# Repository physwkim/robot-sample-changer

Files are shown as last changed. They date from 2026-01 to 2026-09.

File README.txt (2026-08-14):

================================================================================
                    UR3e + Robotiq HandE 로봇 시스템
                       순수 Rust 스택 (ROS 없음)
================================================================================

1. 개요
--------------------------------------------------------------------------------
이 시스템은 UR3e 로봇 암과 Robotiq HandE 그리퍼로 자동화된 샘플 홀더 교환
시퀀스를 수행합니다. 제어는 단일 Rust 데몬(robot-sequencer)이 담당합니다:

    - 로봇 구동: ur-driver (RTDE, 로봇에 직접 접속 — ROS 드라이버 대체)
    - 모션 플래닝/IK: cspace (Rust MoveIt 포트 — MoveIt 대체)
    - 그리퍼: robotiq-hande (TCP 54321 직접 Modbus RTU)
    - 외부 연동: EPICS CA (epics-ca-rs — robot_ioc의 PV 읽기/쓰기)

ROS2/MoveIt/colcon은 더 이상 필요 없습니다.

2. 시스템 요구사항
--------------------------------------------------------------------------------
- Ubuntu 22.04
- Rust toolchain (cargo)
- sibling 체크아웃: ~/ur-driver, ~/cspace, ~/epics-rs (robot_sequencer 빌드용)
- UR 로봇 IP: 192.168.192.10
- 로봇은 Remote Control 모드 (펜던트 프로그램 실행 불필요 — 데몬이
  headless로 external control 프로그램을 전송)

3. 빌드 방법
--------------------------------------------------------------------------------
    export PATH="$HOME/.cargo/bin:$PATH"
    cd ~/ws/src/robot_sequencer
    cargo build --release

EPICS IOC(robot_ioc)와 모니터링 IOC는 별도 빌드:

    cd ~/ws/src/epics_rs_robot && cargo build --release -p robot_ioc
    cd ~/work/epics-rs-iocs && cargo build --release -p ur-robot-ioc

4. 실행 방법
--------------------------------------------------------------------------------
[1] EPICS IOC — 보통 systemd로 자동 실행됩니다 (procServ 콘솔 20001).
    수동 실행: ~/ws/src/epics_rs_robot/target/release/robot_ioc

[2] robot-sequencer 데몬 — 바탕화면 "1_Robot_Sequencer" 아이콘, 또는:

    ~/ws/src/robot_sequencer/target/release/robot-sequencer \
        ~/ws/config/sequencer.yaml

    시작하면 EPICS trigger 대기 상태가 됩니다. 로봇이 켜져 있고
    Remote Control 모드여야 합니다.

[3] Robot GUI (선택) — 바탕화면 "2_Robot_GUI" 아이콘 (conda env 자동).

[4] UR 모니터링 IOC (선택, 읽기 전용) — deploy/ur_monitor_ioc/ 참고.
    Robot:UR: prefix로 로봇 모드/조인트/TCP 상태를 CA로 노출.

URSim 리허설(하드웨어 없이 테스트): config/sequencer_ursim.yaml 사용.

5. 좌표계 설명
--------------------------------------------------------------------------------
이 시스템에서는 두 가지 좌표계를 사용합니다:

[Global Frame - 로봇 베이스 기준 좌표계]

    로봇을 정면에서 바라볼 때:

         Z (위)
         |
         |
         +------ Y (왼쪽)
        /
       /
      X (앞쪽, 로봇이 바라보는 방향)

    - X축: 로봇 전방 (Forward)
    - Y축: 로봇 왼쪽 (Left)
    - Z축: 위쪽 (Up, 중력 반대 방향)

[Local Frame - 엔드이펙터(TCP) 기준 좌표계]

    그리퍼 끝에서 바라볼 때:

         Y (아래)
         |
         |
         +------ X (오른쪽)
        /
       /
      Z (진행 방향, 그리퍼가 접근하는 방향)

    - X축: 오른쪽 (Right)
    - Y축: 아래쪽 (Down)
    - Z축: 진행 방향 (Forward/Approach)

* 주의: Local Frame은 엔드이펙터 기준이므로, 로봇 자세에 따라
  Global Frame과 방향이 다릅니다.

6. Waypoint 설정 방법
--------------------------------------------------------------------------------
웨이포인트 설정 파일 위치:
    ~/ws/config/taught_waypoints.yaml

[기본 웨이포인트 - 직접 티칭 필요]

4개의 기본 위치를 티칭해야 합니다:

    1. holder1_standby       - 홀더1 대기 위치
    2. holder1_on_position   - 홀더1 샘플 집는 위치
    3. sample_holder_standby - 샘플홀더 대기 위치
    4. sample_holder_on_position - 샘플홀더 놓는 위치

조인트 값 순서 (7개):
    [gripper, shoulder_pan, wrist_3, wrist_2, wrist_1, elbow, shoulder_lift]

[웨이포인트 티칭 방법]

1. 로봇을 원하는 위치로 수동 조작 (Freedrive 모드 사용)

2. 현재 조인트 값 확인 (택 1):
   - 티치펜던트의 Move 화면에서 조인트 값 읽기
   - 모니터링 IOC 실행 중이면:
       caget Robot:UR:Receive:ActualJointPositions
     (순서: shoulder_pan, shoulder_lift, elbow, wrist_1, wrist_2, wrist_3
      — 파일 순서와 다르므로 주의)

3. taught_waypoints.yaml 파일에서 해당 위치 값 수정

예시:
    holder1_on_position: [0.024, -1.327, 0.0001, -1.330, -3.301, -1.380, -1.600]

[오프셋 설정 - 미세 조정용]

티칭 후 미세 조정이 필요할 때 오프셋을 사용합니다 (단위: 미터):

    # Holder1 위치 오프셋 (Local Frame 기준)
    holder1_on_position_x_offset: 0.0015   # X축 오프셋 (+: 오른쪽)
    holder1_on_position_y_offset: 0.0      # Y축 오프셋 (+: 아래쪽)
    holder1_on_position_z_offset: -0.0005  # Z축 오프셋 (+: 진행방향)

    # Sample holder 위치 오프셋 (Local Frame 기준)
    sample_holder_on_position_x_offset: 0.0015
    sample_holder_on_position_y_offset: -0.0005
    sample_holder_on_position_z_offset: -0.0005

[자동 계산 웨이포인트]

다음 웨이포인트는 on_position에서 자동 계산됩니다:

    - above: on_position에서 Y 방향으로 5mm 위로 이동
    - retreat: above에서 Z 방향으로 50mm 후퇴

    above_y_offset: -0.005   # -5mm (Local Y, 위로)
    retreat_z_offset: -0.05  # -50mm (Local Z, 후퇴)

[멀티 홀더 오프셋]

홀더 2~10번에 대한 추가 오프셋 (홀더1 기준 상대값):

    # X축 추가 오프셋 (Index 0 = 홀더2, Index 8 = 홀더10)
    holder_multi_x_offsets: [0.000, 0.000, 0.000, 0.000, 0.0015, ...]

    # Z축 추가 오프셋
    holder_multi_z_offsets: [0.00025, 0.00020, 0.00020, ...]

[설정 변경 후]

트리거마다 파일을 다시 읽으므로 데몬 재시작이 필요 없습니다.
다음 Trigger=1 부터 새 값이 적용됩니다.

7. EPICS PV 제어 방법
--------------------------------------------------------------------------------
caput/caget으로 로봇을 제어할 수 있습니다:

시퀀스 시작:
    caput Robot:Trigger 1

시퀀스 일시정지 / 재개:
    caput Robot:Stop 1     # 현재 스텝 완료 후 일시정지
    caput Robot:Stop 0     # 재개

현재 스텝 확인:
    caget Robot:CurrentStep

홀더 번호 설정 (1-10):
    caput Robot:Holder 1

시작 스텝 설정:
    caput Robot:StartStep 0

지정 스텝에서 일시정지:
    caput Robot:PauseStep 15   # 스텝 15 완료 후 멈춤; 다른 값으로 바꾸면 재개

측정 대기 해제 (스텝 12 후):
    caput Robot:Wait 1     # 계속 (스텝 13-23 진행)
    caput Robot:Wait 2     # 나머지 스텝 skip

캘리브레이션 모드 설정:
    caput Robot:CalibMode 0    # 일반 모드 (전체 시퀀스)
    caput Robot:CalibMode 1    # Holder 캘리브레이션
    caput Robot:CalibMode 2    # Sample Holder 캘리브레이션

8. 캘리브레이션 모드 (위치 미세 조정)
--------------------------------------------------------------------------------
홀더 또는 샘플홀더 위치를 미세 조정할 때 사용합니다.
시료를 집어서 above 위치에서 멈추므로 중심 정렬을 확인할 수 있습니다.

[Holder 캘리브레이션 모드] (CalibMode = 1)

    목적: 홀더 위치 확인 및 조정
    동작: 스텝 0-5 수행 -> above에서 멈춤 -> 트리거 대기 -> 스텝 20-23 수행

    사용 방법:
    1. caput Robot:CalibMode 1
    2. caput Robot:Holder 5        # 확인할 홀더 번호
    3. caput Robot:Trigger 1       # 시작 -> 스텝 5에서 멈춤
    4. (시료를 잡은 상태에서 정렬 확인, 필요 시 TCP jog 사용)
    5. caput Robot:Trigger 1       # 시료 돌려놓기

[Sample Holder 캘리브레이션 모드] (CalibMode = 2)

    목적: 샘플홀더 위치 확인 및 조정
    동작: 스텝 0-8 수행 -> sample holder above에서 멈춤 -> 트리거 대기
          -> 스텝 16-23 수행

    사용 방법:
    1. caput Robot:CalibMode 2
    2. caput Robot:Holder 1        # 시료를 가져올 홀더 번호
    3. caput Robot:Trigger 1       # 시작 -> 스텝 8에서 멈춤
    4. (시료를 잡은 상태에서 샘플홀더 정렬 확인, 필요 시 TCP jog 사용)
    5. caput Robot:Trigger 1       # 시료 돌려놓기

[TCP Jog - hold 중 미세 이동]

캘리브레이션 hold 중에만 동작합니다. 방향은 TCP(Local Frame) 기준:

    caput Robot:JogStep 1.0    # 스텝 크기 (mm)
    caput Robot:JogX 1         # +X 방향으로 1스텝 (값: -1/0/+1)
    caput Robot:JogY -1
    caput Robot:JogZ 1

Jog PV는 실행 후 자동으로 0으로 리셋됩니다.

캘리브레이션 완료 후:
    caput Robot:CalibMode 0        # 일반 모드로 복귀

9. Vision 미세 보정 (기본 off)
--------------------------------------------------------------------------------
손목 카메라 노드가 Robot:Vision:* PV로 답하면 픽/플레이스 하강 직전
위치를 자동 보정합니다. config의 vision.enabled: true 로 켭니다
(기본 false — 꺼져 있으면 기존 동작과 완전히 동일).

동작 (Normal 모드 전용, 캘리브레이션 모드에는 적용되지 않음):
  - 스텝 1/12 (standby 도착 후): 픽 정렬 측정 → 스텝 2/3, 13/14 에 반영
  - 스텝 7/18 (standby 도착 후): 플레이스 정렬 측정 → 스텝 8/9, 19/20 에 반영
  - 스텝 5/16 상승 후: 그립 오프셋 측정 (다음 플레이스 보정에 합산)
  - 스텝 12/23 (standby 복귀 후): 안착(seating) 확인

측정은 above가 아니라 standby에서 합니다. above에서는 파지점이 480행짜리
화면보다 55행 아래로 투영되고 화면 중앙에는 한 칸 위 홀더가 잡힙니다
(doc/vision_correction_plan.md §12.4). standby에서는 같은 점이 (306, 330),
샘플홀더 시트가 (313, 277)로 중앙 부근입니다.

보정 게이트 (3축 합성 크기 기준):
  - min_correction (기본 0.05mm) 미만: 노이즈로 보고 무시
  - max_correction (기본 3.0mm) 이하: 적용
  - 초과: 에러 정지 — 자동 적용하지 않음. CurrentStep이 보존되므로
    원인 확인 후 아래 10. 재개 절차대로 StartStep으로 재개

vision.observe_only: true 면 측정하고 로그만 남기며 절대 이동/정지하지
않습니다 (카메라 검증 단계용).

카메라 없이 리허설: vision_sim이 고정 답으로 핸드셰이크에 응답합니다.
    ./target/release/vision_sim --dx 0.8 --dy -0.5

10. 충돌/중단 후 재개 (resume)
--------------------------------------------------------------------------------
상태는 EPICS PV에 보존됩니다 (autosave 포함 — 전원 재시작에도 유지).
CurrentStep > 0 이면 중단된 시퀀스입니다.

    1. caget Robot:CurrentStep         # 중단 지점 확인
    2. caput Robot:StartStep <스텝>    # 재개할 스텝 설정
    3. 프리드라이브로 로봇을 안전한 위치로 이동
    4. 티치펜던트에서 보호정지(protective stop) 해제
    5. caput Robot:Trigger 1           # 재개 (StartStep 미만 스텝 자동 skip)

11. 종료 방법
--------------------------------------------------------------------------------
robot-sequencer: 터미널 실행 시 Ctrl+C, 런처 실행 시 프로세스 종료.
robot_ioc(systemd): sudo systemctl stop robot-ioc

12. 문제 해결
--------------------------------------------------------------------------------
문제: 데몬이 "RTDE init: Input variable ... controlled by another RTDE client"
      오류로 종료됨
해결: 이전 robot-sequencer 프로세스가 남아 있는지 확인 후 종료
      (pgrep -a robot-sequencer). 모니터링 IOC는 receive 전용이라 무관.

문제: 로봇이 움직이지 않음
해결:
  1. 로봇이 Remote Control 모드인지 확인
  2. 보호정지/비상정지 상태 확인 (데몬이 시작 시 보호정지는 자동 해제 시도)
  3. 데몬 로그에서 bring-up 오류 확인

문제: 그리퍼가 동작하지 않음
해결:
  1. 펜던트에서 툴 통신 설정(RS485, 115200) 확인
  2. 로봇 IP로 TCP 54321 접속 가능한지 확인
  3. 다른 프로세스(이전 데몬)가 54321을 점유 중인지 확인

문제: PV가 보이지 않음 (caget 실패)
해결:
  1. robot_ioc 실행 확인 (telnet localhost 20001)
  2. 이 호스트에는 5064를 공유하는 CA 서버가 여럿 있습니다(d435i-ioc 등).
     ss -ulnp | grep 5064 로 확인. 로컬 고정이 필요하면
     export EPICS_CA_NAME_SERVERS=127.0.0.1:5064 를 쓰고,
     EPICS_CA_ADDR_LIST=127.0.0.1 은 쓰지 마세요 — search가
     유니캐스트가 되어 엉뚱한 IOC로만 배달됩니다(CLAUDE.md 참고).

문제: "no answer to request N ... within X s" 에러로 정지 (vision 켠 경우)
해결:
  1. 카메라 노드(또는 vision_sim) 실행 여부 확인
  2. 카메라 없이 돌리려면 config에서 vision.enabled: false

13. 폴더 구조
--------------------------------------------------------------------------------
ws/
├── src/
│   ├── robot_sequencer/           - Rust 시퀀스 데몬 (ur-driver + cspace)
│   ├── epics_rs_robot/            - Rust EPICS IOC(robot_ioc) + 배포(deploy)
│   └── robot_gui/                 - EPICS 기반 로봇 제어 GUI (silx/PyQt)
├── model/                         - URDF/SRDF/메쉬 (정적, xacro 불필요)
├── config/                        - sequencer.yaml, taught_waypoints.yaml
├── resources/urscript/            - external control 프로그램, RTDE recipe
├── deploy/ur_monitor_ioc/         - 읽기 전용 UR 모니터링 IOC
├── db/robot.db                    - EPICS IOC 데이터베이스
└── desktop/, scripts/             - 바탕화면 런처

================================================================================

14. 변경 이력
--------------------------------------------------------------------------------

[2026-08-11] Vision 미세 보정 훅 추가 (기본 off)

* Normal 시퀀스의 4개 하강 직전에 손목 카메라 보정 훅 — Robot:Vision:*
  PV 핸드셰이크, 게이트(무시/적용/에러 정지), observe_only 모드.
  섹션 9 참조. vision.enabled: false(기본)면 기존 동작과 동일.
* vision_sim 바이너리 추가 — 카메라 없이 URSim 리허설용 응답 시뮬레이터.

[2026-08-11] ROS 제거 — 순수 Rust 스택 전환 (ros-free 브랜치)

* ROS2/MoveIt 스택 제거, robot_sequencer(Rust 데몬) 하나로 대체
  - ur-driver(RTDE 직접 접속)가 ur_robot_driver 대체 — headless
    external control 전송, 펜던트 프로그램 불필요.
  - cspace(Rust MoveIt 포트)가 MoveIt 대체 — RRTConnect 플래닝 +
    Cartesian 보간 + TOTG 시간 파라미터라이즈, stage 충돌 씬 유지.
  - robotiq-hande가 TCP 54321 직접 Modbus RTU — socat/가상 tty 제거.
  - C++ epics_triggered_sequence의 스텝/일시정지/재개/캘리브레이션/
    그리퍼 settle 로직 전부 이식 (스텝 번호/PV 의미 동일).
* TCP jog를 EPICS PV(JogX/Y/Z, JogStep)로 통합 — 캘리브레이션 hold 중
  CA로 미세 이동 (기존 TCP 소켓 jog 대체).
* 웨이포인트 파일이 ws/config/로 이동, 트리거마다 재로딩(재시작 불필요).
* URSim 리허설 설정(sequencer_ursim.yaml) 추가 — 하드웨어 없이 전체
  시퀀스/일시정지/skip/재개/캘리브레이션/jog 검증 가능.
* 읽기 전용 UR 모니터링 IOC(deploy/ur_monitor_ioc, Robot:UR: prefix) 추가.

[2026-06-01] EPICS 계층 재정비 및 시퀀스 안정화

* 그리퍼(Hand-E) 활성화 실패 수정
  - libmodbus 응답 타임아웃을 2초로 설정 (robotiq_hande_driver).
  - 이중 socat 충돌 제거.
* EPICS IOC 를 Rust(epics-rs) 기반 robot_ioc 로 전환
  - autosave 로 실행 상태 영속화 → 크래시/전원 재시작 후에도 복원.
  - procServ + systemd 로 부팅 자동시작(src/epics_rs_robot/deploy/).
* 시퀀스 노드 안전/안정성 개선
  - 시작 시 Trigger=0 강제, 완료 시 StartStep=0 리셋, 그리퍼 settle 대기.
* 충돌/중단 후 재개(resume) 운영 절차 정립.

================================================================================

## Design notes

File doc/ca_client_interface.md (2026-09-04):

# Channel Access 클라이언트 인터페이스 — 2026-09-04

`CLAUDE.md`는 **무엇이 있는지**를 적는다(PV 표, 모드, 스텝 번호). 이
문서는 **GUI 없이 CA로만 로봇을 부리는 프로그램**이 쓸 수 있게 그
문법을 모은다 — 어떤 레코드에 어떤 숫자를 어떤 순서로 쓰고, 무엇을
읽어 끝났는지·거절됐는지를 판단하는가.

대상은 빔라인 측정 프로그램이다. 장비 앞에 선 사람은 GUI를 쓰고, 이
문서의 절반(티칭·jog·hold)은 애초에 원격에서 할 일이 아니다.

---

## 0. 전제

- **IOC가 `db/robot.db`의 현재 판을 서빙해야 한다.** `Robot:Cmd`·
  `Robot:CmdArg`·`Robot:CmdArg2`는 2026-09-04에 들어갔다. 없는 IOC에서는
  `caput`이 `Channel connect timed out`으로 떨어지고, 데몬은 명령을 아예
  보지 못한다(채널이 optional이라 로그에 한 줄 남기고 넘어간다).
  §7의 옛 방식은 그대로 유효하다.
- **`robot-sequencer` 데몬이 떠 있어야 한다.** IOC만으로는 레코드에 값이
  들어갈 뿐 아무것도 움직이지 않는다. §4로 살아 있는지 먼저 본다.
- **CA 환경변수를 좁히지 말 것.** 이 호스트에는 5064를 공유하는 CA 서버가
  여럿이다(robot_ioc, ur-monitor-ioc, D405 IOC). `EPICS_CA_ADDR_LIST=127.0.0.1`
  + `AUTO_ADDR_LIST=NO`로 유니캐스트 search를 쓰면 커널이 그중 **하나**
  에만 배달해서 엉뚱한 IOC가 받고 `Robot:*`를 못 찾는다. 브로드캐스트
  search를 그대로 두거나, 고정이 필요하면
  `EPICS_CA_NAME_SERVERS=127.0.0.1:5064`(TCP 직결)를 쓴다.

---

## 1. 명령 한 줄 — `Robot:Cmd`

런에 필요한 값은 레코드 넷(`CalibMode`·`StartStep`·`Holder`·`MapSource`)에
있지만 그중 셋은 데몬의 어휘다 — 여덟 모드 중 몇 번인지, 24스텝
스크립트의 몇 번째에서 시작하는지. `Robot:Cmd`는 errand를 이름으로 받고
번호는 데몬이 채운다.

| `Robot:Cmd` | 명령 | `Robot:CmdArg` | `Robot:CmdArg2` |
|---|---|---|---|
| 0 | None — 대기. 데몬이 명령을 집으면 되돌려 놓는 값 | — | — |
| 1 | Mount — 홀더의 퍽을 스테이지로 | 홀더 **1–10** | 안 씀 |
| 2 | Unmount — 스테이지에 **남은** 퍽을 홀더로 | 홀더 **1–10** | 안 씀 |
| 3 | Divert — **이미 든** 퍽을 홀더로 | 홀더 **1–10** | 안 씀 |
| 4 | Move — 홀더에서 홀더로 | 목적지 **1–10** | 출발 **1–10**, 목적지와 달라야 함 |
| 5 | Recover — 보호정지 해제 + 스탠바이 복귀 | 안 씀 | 안 씀 |
| 6 | Grip Null — 그 시트의 티칭 자세 보정 | 시트 **0–10** (0=스테이지) | 소스 **0–10** (0=그 자리 퍽) |

"안 씀"은 무시된다는 뜻이다. 남아 있던 값이 새어 들어가지 않도록 데몬이
0으로 채워 넣는다. Recover만은 `Robot:Holder`에 이미 있는 값을 쓴다 —
멈춘 런의 standby로 돌아가는 것이 일이라 자기 시트가 없다.

데몬이 채우는 값:

| 명령 | CalibMode | StartStep | Holder | MapSource |
|---|---|---|---|---|
| Mount | 0 Normal | 0 | CmdArg | 0 |
| Unmount | 0 Normal | **13** | CmdArg | 0 |
| Divert | 0 Normal | **18** | CmdArg | 0 |
| Move | 7 Holder Transfer | 0 | CmdArg | CmdArg2 |
| Recover | 4 Recover | 0 | (그대로) | 0 |
| Grip Null | 6 Grip Null | 0 | CmdArg | CmdArg2 |

### 쓰는 순서

**인자를 먼저, `Robot:Cmd`를 마지막에.** 데몬은 `Cmd`가 0이 아닌 것을 본
그 패스에서 인자 둘을 읽는다. `Cmd`를 먼저 쓰면 직전 런의 인자가 읽힐 수
있다.

```bash
caput Robot:CmdArg 3 ; caput Robot:Cmd 1                          # 홀더 3 마운트
caput Robot:CmdArg 3 ; caput Robot:Cmd 2                          # 홀더 3으로 언마운트
caput Robot:CmdArg 5 ; caput Robot:Cmd 3                          # 든 퍽을 홀더 5에
caput Robot:CmdArg 7 ; caput Robot:CmdArg2 2 ; caput Robot:Cmd 4  # 홀더 2 → 홀더 7
caput Robot:Cmd 5                                                 # 복구
caput Robot:CmdArg 0 ; caput Robot:CmdArg2 4 ; caput Robot:Cmd 6  # 홀더 4 퍽으로 스테이지 널
```

### 언제 읽히는가

데몬은 **idle 트리거 대기에서만** 이 레코드를 읽는다(100 ms 주기). 읽는
즉시 0으로 되돌리므로 한 번 쓰면 한 번 돈다.

팔이 움직이는 동안, 또는 hold·측정 대기에 서 있는 동안 쓴 명령은
**실행되지 않는다**. 그 대기는 이미 파라미터가 정해진 런 안에 서 있고,
거기서 시작하는 Mount를 요청한 사람은 없다. 그 값은 다음 대기 진입에서
버려지며 데몬 로그에 이름이 남는다(`Dropped Cmd …`). 그러니
**`Robot:State`가 0(Idle)일 때만 보낸다**(§4).

확장 결과는 네 레코드에 되쓴다. 그것이 런의 상태이기 때문이다 — 재개
경로가 `StartStep`·`Holder`를 읽고, autosave가 IOC 재시작 너머로 그걸
나르고, GUI 둘이 그걸로 "무엇이 도는지"를 말한다.

`Robot:Cmd`는 **autosave 대상이 아니다.** 저장된 명령이 IOC 재시작으로
되살아나면 아무도 안 본 사이에 팔이 움직인다.

---

## 2. 거절 — 두 단계

### 2.1 명령 자체가 말이 안 될 때

아무것도 쓰지 않고 거절한다. `Robot:Cmd`만 0으로 돌아가고
`Holder`·`StartStep`·`CalibMode`·`MapSource`는 그대로다. 이유는
`Robot:Status`(39자)에 남는다.

| 상황 | `Robot:Status` |
|---|---|
| Mount/Unmount/Divert의 CmdArg가 0이거나 11 이상 | `Cmd Mount: seat must be 1-10` (명령 이름은 그때 것) |
| Move의 CmdArg2가 1–10 밖 | `Cmd Move: source must be 1-10` |
| Move의 출발 = 목적지 | `Cmd Move: source is the target` |
| Grip Null의 CmdArg가 0–10 밖 | `Cmd Grip Null: seat must be 0-10` |
| Grip Null의 CmdArg2가 0–10 밖 | `Cmd Grip Null: source must be 0-10` |
| `Robot:Cmd`가 7 이상이거나 음수 | `Cmd: no such command` |

### 2.2 명령은 맞지만 런을 시작할 수 없을 때

명령이 확장된 뒤, 팔이 움직이기 **전에** 걸리는 검사가 있다. 역시
아무것도 움직이지 않고 `CurrentStep`·`StartStep`도 그대로다.

| `Robot:Status` | 뜻 |
|---|---|
| `not started: the fingers hold a puck` | 핑거가 퍽을 물고 있는데 이 런은 집기로 시작한다. Divert(3)로 먼저 내려놓는다 |
| `not started: nothing in the fingers` | 핑거가 비었는데 이 런은 놓기로 시작한다. Divert를 빈 손으로 보낸 경우 |
| `not started: fingers shut on nothing` | 핑거가 빈 채로 닫혀 있다. 열어야 한다(GUI Gripper: Open) |

런이 시작한 뒤 멈추면 `Robot:Status`가 `STOP: …`로 시작한다. 흔한 것:

| `STOP: …` | 뜻 |
|---|---|
| `STOP: seat check @…: the seat r…` | 시트가 스텝이 가정한 상태가 아니다(집으러 갔는데 비었거나, 놓으러 갔는데 찼다) |
| `STOP: the fingers hold a puck bef…` | 런 도중에 핑거 상태가 스텝과 어긋났다 |
| `STOP: open_gripper_final: the fin…` | 열기 명령이 먹지 않았다(Hand-E 활성화 상실 의심) |

전문은 데몬 로그에 있다. `stringin`이 39자라 잘리지만 **앞에서부터**
남으므로 어떤 검사가 거절했는지는 항상 보인다.

---

## 3. 마운트 → 측정 → 반납 한 판

**Mount 한 번이 왕복 전부다.** 스텝 0-12가 퍽을 스테이지에 올리고 측정
대기에 서고, `Robot:Wait`에 1을 쓰면 그 **같은 런**이 13-23으로 퍽을 원래
홀더에 되돌린다. 반납을 위해 명령을 다시 보내지 않는다.

```bash
# 1) 데몬이 idle인지 확인
[ "$(caget -t Robot:State)" = "0" ] || exit 1

# 2) 홀더 3 마운트
caput Robot:CmdArg 3
caput Robot:Cmd 1

# 3) 측정 대기까지 기다린다: State=2, Loaded=1
#    (거절이면 State는 0에 머물고 Status가 이유를 말한다)
while [ "$(caget -t Robot:State)" != "2" ]; do
    case "$(caget -t -s Robot:Status)" in
        "Cmd "*|"not started:"*|"STOP: "*) echo "거절/정지: $(caget -t -s Robot:Status)"; exit 1;;
    esac
    sleep 1
done

# 4) 측정한다 … 끝나면 계속 진행 → 팔이 퍽을 홀더 3에 되돌린다
caput Robot:Wait 1

# 5) 반납까지 끝나면 State=0, Status=idle - waiting for a trigger
while [ "$(caget -t Robot:State)" != "0" ]; do sleep 1; done
```

### 측정 대기에서는 `Robot:Cmd`가 안 먹는다

여기서 `Robot:Cmd`에 2(Unmount)를 써도 **아무 일도 일어나지 않는다.**
명령은 idle 트리거 대기에서만 읽히고(§1), 측정 대기는 이미 파라미터가
정해진 런 **안에** 서 있다. 그 자리에서 읽는 것은 `Robot:Wait` 하나다.

```bash
caput Robot:Wait 1    # 계속 — 13-23이 퍽을 홀더로 되돌린다
caput Robot:Wait 2    # 건너뛰기 — 런이 여기서 끝나고 퍽은 스테이지에 남는다
```

써 둔 2는 다음 대기가 열릴 때 버려지고 데몬 로그에 이름이 남는다
(`Dropped Cmd …`). 레코드에 값이 남아 다음 idle에서 뒤늦게 도는 일은
없다.

**Unmount(2)는 그 런이 없어졌을 때** 쓴다 — `Wait=2`로 건너뛰어 퍽을
스테이지에 두고 끝냈거나, 데몬이 죽어 다시 떴거나, `STOP:`으로 멈춘
런을 접었을 때. StartStep 13으로 들어가 스테이지 standby까지 계획해서
간 뒤 13-23으로 퍽을 홀더에 넣는다.

### `Robot:Wait`을 미리 쓰지 말 것

대기는 **열리면서** 명령 레코드를 비운다(`Trigger`·`Wait`·jog·
`Jog:Apply`·`Gripper`). 대기가 열리기 전에 써 둔 1은 그 비움에 지워진다.
`State=2`를 본 뒤에 쓴다.

읽기 규칙은 비대칭이다 — **0만이 "계속 기다려라"이고 2만이 Skip이며,
1도 그 밖의 값도 읽기 실패도 전부 Continue다.** 측정이 끝나지 않았는데
0이 아닌 값이 들어가면 팔이 움직인다.

## 4. 읽는 쪽 — 지금 무슨 일이 일어나는가

| PV | 타입 | 값 |
|---|---|---|
| `Robot:State` | longin | 0=Idle 1=Running 2=MeasWait 3=Paused 4=Hold |
| `Robot:Alive` | longin | 서비스 패스마다 +1. **Running 중에는 멈춘다** |
| `Robot:Status` | stringin | 지금 하는 일, 또는 멈춘 이유 (39자) |
| `Robot:CurrentStep` | longin | 실행 중인 스텝 (0-23) |
| `Robot:Loaded` | bi | 1 = 측정 대기 중(스테이지에 시료가 있다) |
| `Robot:Seat:Stage`, `Robot:Seat:H1`..`H10` | longin | 0=모름 1=빔 2=참 |
| `Robot:Seat:Msg` | stringin | 마지막 시트 검사 한 줄 |
| `Robot:Gripper_RBV` | bi | 0=Close 1=Open |

**데몬이 살아 있는지**는 `State`와 `Alive` 둘로 판단한다:

- `State`가 0/2/3/4(서 있는 상태)인데 `Alive`가 2초 넘게 안 변하면
  데몬이 안 듣는 것이다. 명령을 보내도 소용없다.
- `State=1`(Running)이면 `Alive`가 멈춰 있는 것이 **정상**이다. 일하는
  중이고 명령을 읽지 않는다.

명령을 보내도 되는 조건은 하나다: **`State=0` 이고 `Alive`가 움직인다.**

**시트 레코드는 관측이지 추측이 아니다.** 아무도 가보지 않은 시트는
0(모름)으로 남는다. IOC 재시작 뒤에는 전부 0이다(autosave 대상이 아니다 —
복원된 "참"은 그 사이 손으로 옮긴 퍽을 못 본다).

---

## 5. 명령으로 감싸지 않은 것들

레코드 하나로 끝나는 일은 그대로 쓴다.

| 일 | 쓰기 |
|---|---|
| 측정 계속 | `Robot:Wait` = 1 |
| 남은 스텝 건너뛰기 | `Robot:Wait` = 2 |
| 일시정지 / 해제 | `Robot:Stop` = 1 / 0 |
| 특정 스텝에서 정지 | `Robot:PauseStep` = 스텝 번호 |
| 시트 카메라 검사 끄기/켜기 | `Robot:SeatCheck` = 0 / 1 |

`Stop`·`PauseStep`·`SeatCheck`는 "지금부터 이렇게 두라"는 **레벨**이라
대기가 열려도 지워지지 않는다. `Wait`·`Trigger`·`Cmd`·jog·`Gripper`는
"한 번 하라"는 **one-shot**이라 대기가 열릴 때 비워진다.

`Robot:Stop`은 **스텝 경계에서** 걸린다(다음 스텝 앞에서 선다). 궤적
중간에 팔을 세우지 않는다 — 비상정지는 펜던트의 몫이다. 멈춰 있는 동안
`Robot:Status`가 `paused by Robot:Stop before step N`이라고 말한다.

티칭 모드(`CalibMode` 1 Holder Calib, 2 Sample Holder Calib, 3 Hand-Eye,
5 Seat Probe)는 명령에 넣지 않았다. jog hold에 서서 사람이 손으로 맞추는
일이라 원격 한 줄로 시작할 것이 아니다.

---

## 6. 걸렸을 때

멈춘 런은 `CurrentStep`을 남긴다(불변식: `>0`이면 중단된 시퀀스, `0`이면
idle). 이유는 `Robot:Status`에 있다.

| 증상 | 답 |
|---|---|
| 보호정지 / 충격 감지 | `Robot:Cmd` = 5 (Recover). unlock → 프로그램 재전송 → 스탠바이가 한 번에 된다. 데몬 재시작은 **금지** — Hand-E 재활성화가 파지를 푼다 |
| 스테이지가 차서 스텝 8 앞에서 멈춤 | 든 퍽을 다른 홀더에: `CmdArg`=그 홀더, `Cmd`=3 (Divert) |
| 원래 홀더가 차서 스텝 19 앞에서 멈춤 | 같음 — `Cmd`=3 |
| 스테이지에 퍽이 남아 Normal이 스텝 7에서 멈춤 | `CmdArg`=넣을 홀더, `Cmd`=2 (Unmount) |
| 퍽을 든 채 Mount를 눌러 거절됨 | 먼저 `Cmd`=3으로 내려놓는다 |

**퍽을 든 채로 Mount(1)를 보내면 거절한다**(§2.2). 스텝 0의 열기가 선
자리에서 퍽을 떨구기 때문이다.

중간 스텝에서 직접 재개해야 하면 옛 방식(§7)으로 `StartStep`을 직접 쓴다.
명령 여섯 개는 사람이 쓰는 재개 지점(0·13·18)만 덮는다.

---

## 7. 옛 방식 — 레코드 넷 + 트리거

`Robot:Cmd`가 없는 IOC에서도, 있는 IOC에서도 그대로 동작한다. 명령이
덮지 않는 재개 지점이 필요하면 이쪽을 쓴다.

```bash
caput Robot:Holder 3
caput Robot:CalibMode 0
caput Robot:StartStep 0
caput Robot:Trigger 1
```

`Robot:Trigger`도 one-shot이라 데몬이 집으면서 0으로 되돌린다. 네 값은
**트리거를 집는 그 순간에 한꺼번에** 읽힌다 — 그러니 트리거를 마지막에
쓴다. 두 사람이 각자 준비하다 섞이는 것을 완전히 막지는 못한다(CA에
원자성이 없다). 창이 네 번의 get으로 좁혀져 있을 뿐이다.

`CalibMode` 값: 0 Normal, 1 Holder Calib, 2 Sample Holder Calib,
3 Hand-Eye Calib, 4 Recover, 5 Seat Probe, 6 Grip Null, 7 Holder Transfer.

`StartStep` 재개 지점: 0 처음부터, 13 스테이지에서 회수, 18 든 퍽을 홀더에.

---

## 8. 코드 기준

`db/robot.db`(레코드 셋), `src/robot_sequencer/src/sequence.rs`
(`Command::expand`, `Sequencer::take_command`),
`src/robot_sequencer/src/epics.rs`(채널과 접근자),
`src/robot_sequencer/src/config.rs`(PV 이름 기본값).

명령의 확장 표와 거절 문구는 `sequence.rs`의 테스트
`a_command_expands_to_the_records_an_operator_would_have_set`,
`a_command_refuses_a_seat_its_errand_has_no_use_for`,
`only_the_six_command_codes_name_a_command`가 고정한다. 이 문서의 §1·§2.1
표가 바뀌면 그 테스트가 먼저 깨진다.

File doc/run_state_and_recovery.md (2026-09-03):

# 런 상태 발행과 중단 복구 — 2026-09-03

`CLAUDE.md`는 **무엇이 있는지**를 적는다(PV 표, 모드, 스텝 번호). 이
문서는 2026-09-03에 넣은 것들이 **어떤 질문에 답하려고** 들어갔는지,
그리고 멈춘 런 앞에 선 사람이 실제로 무엇을 눌러야 하는지를 적는다.

코드 기준은 `0547706..0be30c1`, 15 커밋. 전부 이 날짜다.

---

## 1. 출발점 — 멈춘 팔 앞에서 알 수 없던 것

시트 점유 검사(`seat_check`, 2026-08-19)가 들어간 뒤로 런은 **정당한
이유로 멈추기 시작했다**. 스테이지가 차 있으면 스텝 7에서, 넣으려는
홀더가 차 있으면 스텝 18에서 선다. 그게 맞다. 문제는 그 다음이었다:

- **왜 멈췄는지**가 데몬 터미널에만 있었다. 장비 앞에 선 사람은 거기를
  보고 있지 않다.
- **퍽이 어디 있는지**를 화면이 몰랐다. 검사는 방금 봤는데, 그 판정이
  아무 데도 남지 않고 로그로 흘러갔다.
- **버튼이 눌리는 근거**가 런 잔해였다. `CurrentStep == 12`로 Continue를
  열면, 스텝 12에서 죽은 데몬 위에서도, autosave가 12를 복원한 IOC
  위에서도 버튼이 열린다 — 아무도 안 읽는 `Wait`에 쓰게 된다.
- **손에 퍽을 든 채 멈추면** 나갈 길이 Advanced 카드밖에 없었다.

오늘 넣은 것은 전부 이 네 줄에 대한 답이다.

---

## 2. 데몬이 발행하는 것

### 2.1 `Robot:State` / `Robot:Alive` — 버튼의 유일한 게이트

데몬은 **서비스 패스**(`service_hold`)에서만 운전자 명령을 읽는다 —
`Robot:Gripper`, jog, `Jog:Apply`, `Wait`, 두 번째 `Trigger`. 이 패스는
멈춰 서 있는 루프에서만 돌고 팔이 움직이는 동안에는 돌지 않는다.
그래서 GUI 컨트롤은 **`State`(어느 루프인지) + `Alive`(아직 그 말을
하고 있는지) 둘로만** 열린다. `Alive`가 2초(서비스 패스 20회) 멈추면
그 컨트롤을 회색 처리한다.

`State=1`(Running)일 때 `Alive`가 멈추는 것은 정상이다. 그래서 데몬은
**막히는 일 앞뒤로 Running을 찍는다**(`while_moving`) — 스텝 실행뿐
아니라 서비스 패스 안의 jog 모션과 그리퍼 명령까지. 덕분에 규칙이
하나로 줄어든다: *Running이면 조용한 게 정상, 서 있는 상태인데 조용하면
죽은 것.*

쓰는 주인은 `set_state` 하나뿐이고, 항상 현재 beat와 같이 쓴다.
(`8b899a5`)

### 2.2 `Robot:Status` — 왜 서 있는지

`State`가 숫자로 "어느 루프"를 말한다면 이건 **문장**이다.

- 평상시: `step 9: sample_holder_on_position`,
  `measuring - Wait=1 to continue`, `hold @holder 3: trigger to return`
- 멈추면: `STOP: seat check @the stage: the seat r…`,
  `not started: fingers shut on nothing`

두 가지가 설계의 전부다.

1. **멈춘 이유는 다음 트리거 대기에서도 그대로 남는다.** 이유를 쓰고
   바로 `Idle`로 덮으면 "아무 일 없음"이 되는데, 실패 직후에 그건
   유일하게 틀린 답이다. 데몬은 트리거 대기에 들어갈 때마다 자기가 들고
   있는 `idle_status`를 다시 쓴다.
2. **서비스 패스마다 다시 쓴다.** 대기 중에 IOC를 재시작하면 레코드가
   db 기본값(`no daemon`)으로 돌아온다. 바뀔 때만 쓰는 데몬이면 살아서
   서 있는 데몬 위에 "no daemon"이 그대로 남는다.

`stringin`이라 39자다. 에러 문장은 **앞에서부터** 남으므로, 어떤
검사·어떤 이동이 거부했는지가 먼저 오도록 메시지를 쓴다. 전문은 로그에
그대로 있다. 쓰는 주인은 `set_status` 하나뿐이다. (`3899bf4`)

### 2.3 `Robot:Seat:*` — 퍽이 어디 있나

시트 11개(스테이지 + 홀더 1-10)마다 longin 하나: 0=모름, 1=빔, 2=참.
**둘 다 관측이고 추측은 없다.**

- `seat_check` 게이트가 시트에 들어가기 전에 읽은 판정. 스텝이 기대한
  값과 달라 런이 멈추는 경우에도 **본 대로** 쓴다 — 그 시트가 바로
  운전자가 봐야 할 시트라서.
- 시퀀스 자신이 아는 것: 퍽을 들어올린 시트는 빔(스텝 5·16), 놓은
  시트는 참(스텝 10·21). 재개로 **건너뛴 스텝은 쓰지 않는다**. 홀더 간
  이동(모드 7)과 그립 널의 가져오기도 같은 두 지점에서 쓴다.

`Robot:Seat:Msg`는 그 판정 **뒤에 있는 읽음**이다 —
`holder 3: occupied -4.5mm 71%`. 판정이 안 나오는 경우도 여기로 나간다
(`check switched off`, `no camera IOC`, `no depth frame`,
`not in the frame`, `unreadable, 7% valid`). (`7189576`)

### 2.4 셋 다 autosave가 아니다 — 그게 요점이다

`CurrentStep`·`Loaded`·`Jog:Target`은 재개용 마커라 데몬보다 오래
살아남아야 하고, IOC가 autosave에서 복원까지 한다. 오늘 넣은 셋은
반대다:

- `State`/`Alive`: 죽은 데몬의 상태를 복원해 보여주면 버튼이 열린다.
- `Status`: 죽은 데몬의 상태를 복원해 보여주는 건 `State`가 막으려는
  바로 그 거짓말이다.
- `Seat:*`: IOC 재시작 뒤에는 아무도 안 본 게 맞다. 복원된 "참"은 그
  사이 손으로 옮긴 퍽을 못 본다.

---

## 3. GUI가 그것으로 하는 것

- **State 카드 `Daemon` 줄** — 듣고 있나(`State`+`Alive`).
- **State 카드 `Doing` 줄** — 무엇을 하고 있나(`Robot:Status`). 멈춘 런
  뒤에는 화면에서 이유를 말하는 유일한 자리다.
- **Seats 카드** — `Robot:Seat:*` 열한 개를 칩으로. 초록 = 퍽, 회색 =
  빔, 어두움 = 아직 아무도 안 봄. 레코드가 아예 없어도 같은 어두움이고,
  툴팁이 IOC 재시작을 지목한다. 칩 아래 `last check —` 줄이
  `Robot:Seat:Msg`.
- **모든 컨트롤의 게이트가 `State`+`Alive`로 통일됐다.** 런 값
  (`CurrentStep`, `Jog:Target`)은 라벨(어느 시트인지)에만 쓰고 게이트에는
  쓰지 않는다. (`src/robot_gui_rs/src/daemon.rs`)

---

## 4. 런이 시작하기 전에 거부하는 것

### 4.1 `empty_close` — 빈 손으로 시트에 들어가지 않는다

시트에 들어가는 모드의 모든 다리는 두 가지 중 하나로 시작한다: 집기(
핑거가 열려 있어야 함) 또는 나르기(퍽을 물고 있어야 함). **아무것도 안
물고 닫혀 있는 핑거**는 둘 다 아니고, 다음 스텝들은 그 상태로 시트에
들어간다. 그렇게 되는 흔한 경로 둘 — `StartStep` 재개가 스텝 0의 열기를
건너뛰는 것, GUI의 수동 Close.

**런의 첫 모션 전에 거부**하고 고치지 않는다. 핑거를 여는 건 운전자의
판단이다(무엇을 물고 있는지 데몬은 모른다). 팔을 움직이며 시작하는
런이야말로 이 검사가 막으려는 것이다. (`809ca97`)

### 4.2 `Robot:SeatCheck` — 끄는 스위치는 사람 손에

`sequencer.yaml`의 `seat_check.enabled`는 검사가 **존재하는지**를 정하고
(핸드아이 파일을 읽는다), 이 레코드는 그게 **도는지**를 정한다. 데몬이
게이트마다 한 번 읽으므로 런 도중에 꺼도 다음 시트부터 듣는다.

읽기가 실패하면(레코드 없음, 타임아웃) **켜짐**으로 답한다. autosave에
넣지 않은 것도 같은 이유다 — 꺼둔 안전 검사가 IOC 재시작으로 조용히
되살아나거나 조용히 꺼져 있으면 안 된다. 레코드는 On으로 올라온다.
(`491d76f`)

### 4.3 `resume_approach` — 재개는 그 다리의 standby부터

`StartStep`으로 다리 중간에 들어가면 첫 카테시안 스텝은 팔이 지금 어디
있든 직선으로 간다. 재개 전에 그 다리의 standby까지 **계획 이동**을 먼저
넣는다. 다리별 매핑은 `LegStandby::for_resume`:

| StartStep | 접근 |
|---|---|
| 2-6 | 랙 standby (집기) |
| 8-17 | 스테이지 standby (놓기 + 집기, 두 다리가 같은 standby) |
| 19-23 | 랙 standby (놓기) |
| 0·1·7·18 | 없음 — 그 스텝 자신이 standby로 가는 계획 이동이다 |

(`b75e93a`, 그리고 계획 실패 메시지가 어느 끝인지 말하도록 `ee36bb6`)

---

## 5. 중단된 런 — 어디서 멈췄나, 무엇을 누르나

`Robot:Status`가 어디서 멈췄는지 말한다. 팔의 상태는 그것으로 결정된다.
게이트 넷은 스텝 **1·7·12·18을 마친 직후**에 서므로 `CurrentStep`은 그
번호로 남는다(다음 스텝 2·8·13·19는 실행되지 않았다).

| 멈춘 곳 | 팔의 상태 | 답 |
|---|---|-----|
| 스텝 1 뒤 (`seat check @holder N: empty`) | 빈 손, 랙 standby | 퍽이 있는 홀더로 `Holder`를 고쳐 다시 트리거 |
| 스텝 7 뒤 (`seat check @the stage: occupied`) | **퍽을 문 채** 스테이지 standby | ① 빈 홀더로 **Put carried puck in holder** ② 그 다음 **Return from stage**로 스테이지를 비움 |
| 스텝 12 뒤 measurement wait | 빈 손, 스테이지 standby | Continue(회수) 또는 Abort |
| 스텝 12 뒤 (`seat check @the stage: empty`) | 빈 손, 스테이지 standby | 스테이지에 퍽이 없다 — 어디로 갔는지 확인 |
| 스텝 18 뒤 (`seat check @holder N: occupied`) | **퍽을 문 채** 랙 standby | 다른 빈 홀더로 **Put carried puck in holder** |
| 보호정지(충격) | 어디든 | `CalibMode=4`(Recover) 트리거 — unlock → 프로그램 재전송 → 스탠바이 |

### 5.1 "Put carried puck in holder" (`Action::Divert`)

Sample 카드, "Return from stage" 아래. 위 `Holder` 값을 목적지로 삼아
`Holder=N`, `CalibMode=0`, `StartStep=18`, `PauseStep=0`, `Wait=0`,
`Trigger=1`을 쓴다.

스텝 18이 그 홀더 standby까지 계획해서 가고, 19-23이 놓는다. **집는
다리(0-6, 13-17)는 전부 건너뛰므로 손에 든 퍽을 놓지 않는다.** 새
홀더가 비었는지는 스텝 18의 `seat_check`가 다시 본다. 원래 홀더로
되돌리는 것도 같은 버튼이다 — 스텝 5에서 비웠으므로 그 시트는 비어
있다. (`0be30c1`)

### 5.2 순서가 반대면 안 된다

**퍽을 든 채 `StartStep=13`(Return)을 누르지 말 것.** 스텝 12 뒤의
`seat_gate`는 "스테이지에 퍽 있음"을 기대하므로 통과하고, 스텝 13-14가
퍽을 문 핑거로 스테이지 퍽 위로 내려간다. `empty_close`는 "빈 손으로 닫힘"만
막지 이건 못 막는다. 손에 든 퍽을 먼저 내려놓는다(§5.1).

### 5.3 구 Python GUI도 같은 값을 쓴다

`_return`이 아직 `StartStep=7`을 쓰고 있었다 — 회수 다리의 진입점이 7에서
13으로 바뀐 뒤로 스테이지에 놓는 다리를 다시 실행하는(시트에 내려가
빈손으로 여는) 값이었다. 13으로 고쳤고, "wait에서 Continue를 누르라"던
안내 문구도 같이 고쳤다(그 errand는 wait에 닿지 않는다). (`292477f`)

---

## 6. 시트 체크 창을 시트마다 옮긴다

창은 시트 자세를 따라가지만, **퍽 윗면이 그 자세 어디에 보이는지는
시트마다 다르다**. 창의 툴 y −6…+2 mm는 랙에서 잰 값이고, 스테이지를
옮겨 트림으로 다시 티칭한 뒤로는 스테이지 퍽 윗면이 창 맨 아랫줄에 걸려
중앙값이 50 mm 뒤 배경을 읽었다.

그래서 시트별 **창 바이어스**를 둔다(`seat_check.rack_window_bias_mm` /
`stage_window_bias_mm`, 시트의 툴 프레임 mm). 옮기는 것은 **샘플링 창
뿐**이고 판정 기준인 파지점도, 팔이 가는 자세도 그대로다 — 트림은 팔이
가는 곳이라 창을 맞추려고 건드리면 안 된다.

앉은 퍽으로 실측(스테이지):

| 바이어스 | 판정값 |
|---|---|
| +0 mm | +53.1 (비움) |
| +2 mm | +43.2 (비움) |
| +4 mm | −8.2 |
| +6 mm | −7.9 |
| +8 mm | −7.3 |
| +10 mm | −7.3 |

가장자리가 +3이고 플래토가 +10 너머까지 가므로 **+8 mm**(유효 픽셀 74%),
랙은 0이다. `seat_scan <cfg> stage 1 bias:0,8,0`이 라이브 프레임으로
다시 잰다.

게이트가 자기가 검사하는 시트를 라벨 문자열이 아니라 `Seat` 값으로
받게 바꾼 것이 이 바이어스의 전제다(`0beb79f`, `f23e6a8`).

---

## 7. 스테이지를 옮겼다 (2026-09-03)

세 곳이 같이 움직여야 한다 — 시트 트림, 충돌 씬, 시트 체크 창.

1. **트림** — `sample_holder_on_position_{x,y,z}_offset`. jog + Apply로
   쓴다(툴 프레임 mm). 이번 값 (−8.4246, −1.5, +4.4842) mm.
2. **충돌 씬** — `sequencer.yaml`의 `scene.objects` 40개가 전부 같은
   `position`을 쓰는 스테이지 한 덩어리. 트림 변화량을 **모델 좌표로
   돌려서** 그만큼 더한다. 위 트림은 모델 좌표로
   [−0.00431, −0.00849, +0.00162] m였다
   (`seat_scan config/sequencer.yaml stage 1 <dx,dy,dz mm>`가 환산을
   찍는다).
3. **시트 체크 창** — `stage_window_bias_mm` (§6).

트림은 한 점이 어디로 갔는지만 말하므로 **스테이지가 돌아갔다면 rpy는
트림으로 알 수 없다.** 씬과 창은 둘 다 `sequencer.yaml`이라 **데몬
재시작**이 필요하다(트림은 트리거마다 다시 읽는다). (`a0c10d3`)

랙 깊이(툴 y) 트림 둘은 0으로 되돌리고 h5·h9·h10을 다시 썼다. 깊이는
이제 어느 시트에서도 그립 널이 조향하지 않으므로, 조향하던 시절에 남은
그 두 값은 아무도 갱신해 주지 않는 값이었다. 측방·z 변화는
0.006-0.053 mm로 재티칭이 아니라 그립 널 스케일이다. (`765d50c`)

---

## 8. 그립 널의 대상이 스테이지까지 (`CalibMode=6`)

전에는 가져오기가 랙↔랙이었고, 스테이지는 "이미 앉아 있는 퍽"만 쓸 수
있었다. 즉 스테이지를 널하려면 Normal 런을 먼저 한 번 돌려야 했다.

이유는 기능이 아니라 코드였다 — 놓는 다리가 랙용으로 쓰여 있었다.
`carry_puck`에 목적지 `Seat`를 주면 스텝 번호 표가 갈린다:

| 목적지 | 놓는 스텝 |
|---|---|
| 스테이지 | 7-12 |
| 랙 홀더 | 18-23 |

이제 대상은 두 시트 다 되고, `MapSource`의 소스는 여전히 랙 홀더뿐이다
— `MapSource=0`이 "제자리 퍽"에 이미 쓰이고 있어서 스테이지를 가리킬
번호가 없다. 널이 끝나면 퍽은 **대상 시트에 남는다**. 스테이지에 널했다면
거기 놓인 채이므로 되돌리는 건 Return이다. (`c99c32a`)

---

## 9. 그 밖에

`Robot:Loaded`를 내리는 주인을 회수 다리 하나로 모았다. 스텝 12 뒤
measurement wait에서 1이 서고, **wait 지점을 지나는 모든 경로에서** 0이
된다 — continue, skip, 그리고 wait 자체가 없는 회수
errand(`StartStep=13`)까지. 회수 errand가 0을 쓰는 이유는 그 1을 세운
마운트 런이 wait에서 끝났기 때문이다. (`5d1ee1b`)

---

## 10. 커밋

```
ee36bb6 motion: name which end of a planned move is invalid
b75e93a seq: plan to a resumed leg's standby in resume_approach
809ca97 seq: check empty_close before a seat-entering run starts
5d1ee1b seq: write_loaded(0) past the measurement wait, not inside it
8b899a5 seq: publish Robot:State and Robot:Alive from a single set_state
491d76f seq: add Robot:SeatCheck, read at every seat gate
0beb79f seq: give seat_gate the Seat it is checking, not a label
f23e6a8 seq: bias the seat-check window per seat, +8 mm at the stage
a0c10d3 config: move the stage scene and its seat trims to where it now stands
765d50c config: zero the rack depth trims and refresh h5, h9 and h10
c99c32a grip null: let the target seat be the stage, fetch and all
3899bf4 seq: add Robot:Status, the daemon's own account of itself
7189576 seq: add Robot:Seat:*, where the pucks are as far as anything looked
292477f gui: enter the return errand at step 13 in the Python GUI too
0be30c1 gui: add Action::Divert, place a carried puck in another holder
```

IOC db에 레코드 셋(`Robot:Status`, `Robot:Seat:*` 열둘)이 추가됐으므로
**robot_ioc 재시작이 필요하다**. 데몬은 레코드가 없으면 조용히 발행을
건너뛰므로 순서는 상관없지만, 재시작 전까지 GUI의 Doing 줄과 Seats 칩은
비어 있다.

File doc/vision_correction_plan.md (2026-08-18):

# 카메라 보정 구현 계획 — eye-in-hand D405

기존 `vision_inspection_plan.md` / `vision_camera_setup.md`를 **대체하지 않고
전제를 정정한다.** 두 문서는 외부 고정 카메라를 전제로 쓰였고, 실물은 그것이
아니다 (§0). 측정 원리·태그 운용·안착 판정 논의는 그대로 유효하므로 계속
참조한다. 바뀌는 것은 **캘리브레이션 형식과 측정 흐름**이다.

---

## 0. 전제 정정 — 문서와 실물의 불일치

`vision_inspection_plan.md:206`은 이렇게 확정하고 있다:

> **확정 사항 (Rev 3): 외부 고정 카메라 1대 + AprilTag(tag36h11)를 쓴다.**

그리고 `:217`에서 eye-in-hand(M1)를 "손목 D405를 병용할 때만 필요. 외부
카메라만 쓰면 **불필요**"로, `:222`에서 "손목에 카메라가 없으므로"라고 적었다.

**실측 결과 이 전제가 성립하지 않는다.**

| 항목 | 문서 전제 | 실측 |
|---|---|---|
| 카메라 대수 | 외부 고정 1대 | **D405 1대뿐** (`lsusb`: `8086:0b5b`, serial `315122272475`) |
| 장착 | 브레드보드 고정 | **손목 장착** (사용자 확인) |
| 캘리브레이션 | eye-to-hand → `T_base_cam` | **eye-in-hand → `T_ee_cam`** |
| 외부 카메라 | 존재 전제 | **존재하지 않음** |

문서는 8/12 작성, AprilTag 시트(`doc/apriltags/`, 바닥 100 mm 태그 + 홀더
10 mm 태그)는 8/13 작성이다. 태그 구성 자체가 이미 eye-in-hand 배치다 —
**고정 태그 + 움직이는 카메라**. 즉 실제 작업은 이미 eye-in-hand로 갔고
문서만 남아 있다.

**이 계획은 eye-in-hand를 기준으로 한다.** 외부 카메라가 나중에 추가되면
§6에 적은 대로 이 계획 위에 얹는다 (버리는 작업 없음).

### 0.1 전제가 바뀌면서 좋아지는 것

문서가 걱정하던 두 문제가 **사라진다**:

- **로봇 팔 가림** (`vision_camera_setup.md:142`, "30° 비스듬") — 카메라가
  손에 있으므로 팔이 시야를 가릴 일이 없다. 마운트 각도 타협이 불필요하다.
- **랙과 측정 홀더를 한 시야에** (`:529`) — 카메라가 따라가므로 한 대로
  둘 다 본다. 배치 제약이 없다.

그리고 결정적으로:

**기존 `Robot:Vision:DX/DY/DZ` 훅이 eye-in-hand 출력과 정확히 맞는다.**

```rust
// sequence.rs:505 — 보정은 TCP-local 프레임
self.model.apply_cartesian_offset(base, offset, /* z_global */ false, label)
```

`corrected()`는 티칭 웨이포인트의 FK 포즈에 **TCP 로컬**로 offset을 곱한다.
eye-in-hand 카메라의 측정값은 툴에 붙어 있으므로 그대로 TCP-local이다.
외부 고정 카메라였다면 base 경유 변환이 필요했고, 그 변환에
`T_base_cam` 오차가 통째로 실렸을 것이다. **훅을 고칠 필요가 없다.**

---

## 1. 현재 상태 인벤토리

### 1.1 이미 있는 것 (재사용)

| 항목 | 위치 | 상태 |
|---|---|---|
| D405 EPICS IOC | `d405-ioc.service` (epics-rs-iocs) | **가동 중.** `RS405:` prefix |
| 컬러 스트림 | `RS405:image1:` | 640×480, RGB1/UInt8, 15 fps |
| 깊이 스트림 | `RS405:depth1:` | 640×480, depth unit **0.0001 m** (D405 고유) |
| PVA 서버 | port 5085 | 이미지 전송 경로 |
| 시퀀서 비전 훅 | `sequence.rs:195-276` | 4종 8지점 배선 완료, `enabled: false` |
| 핸드셰이크 프로토콜 | `Robot:Vision:Req/Kind/Done/Valid/DX/DY/DZ/Quality/Seated/Tilt` | IOC 서빙 중 |
| 보정 적용 | `sequence.rs:496` `corrected()` → `model.rs:133` | TCP-local, IK 재해 |
| 관찰 모드 | `config.rs:196` `observe_only` | 측정·로그만, 이동 없음 |
| 리허설 대역 | `src/bin/vision_sim.rs` | 카메라 없이 프로토콜 검증 |
| AprilTag 시트 | `doc/apriltags/` | id 0 @100 mm, id 1–11 @10 mm, 시험띠 100–104 @10~30 mm |
| 구 hand-eye 코드 | `git show main:src/realsense_service/.../hand_eye_calibration_node.py` | ROS2, 574줄. **수식은 이식 가능** |

### 1.2 없는 것 (만들어야 함)

| 항목 | 왜 필요 | 난이도 |
|---|---|---|
| **카메라 내부 파라미터 공급** | 없으면 거리가 전부 틀림 | 소 (§2.1) |
| **비전 노드** | 저장소에 구현이 0. 문서와 태그 생성기뿐 | 중 |
| **`T_ee_cam`** | 미측정 | 중 (§3) |
| **URDF 카메라 링크** | `model/urdf/*.urdf`에 camera 없음 | 소 |
| **scene 런타임 갱신 경로** | `load_scene_assets`는 connect 전용 (`bringup.rs:46`) | 중 (§5) |

### 1.3 구 hand-eye 코드의 함정 (이식 전 반드시 고칠 것)

```python
# hand_eye_calibration_node.py:80-85
self.camera_matrix = np.array([...])   # D405 값 하드코딩
self.dist_coeffs   = np.zeros(5)       # "RealSense는 왜곡 보정된 이미지 제공"
```

- **하드코딩 intrinsics** — 개체마다 다르다. 실제 장치에서 읽어야 한다.
- **`invert_gripper2base`** (`:463`) — eye-to-hand용 역변환 플래그.
  **eye-in-hand에서는 `False`**. 켜면 조용히 틀린 답이 나온다.
- ArUco `DICT_6X6_250` / `marker_size 0.05` — 새 태그는 tag36h11이다.

---

## 2. 좌표계와 미지수

```
        T_base_ee        FK로 계산 (관절각 → 기지)
   base ──────────► ee ──────────► cam ──────────► tag
                    T_ee_cam        T_cam_tag
                    ▲               ▲
                    │               └── 매 프레임 측정 (solvePnP)
                    └── 미지수. 1회 캘리브레이션 (§3)
```

**보정에 실제로 필요한 것은 절대 포즈가 아니다.** 티칭된 `above` 자세에서
태그를 보고, "기대 위치 대비 얼마나 어긋났나"만 구한다:

```
d_cam   = T_cam_tag(측정) 의 위치 − T_cam_tag(기준, 티칭 시 저장) 의 위치
d_tcp   = R_ee_cam · d_cam                    ← 회전만 쓴다
→ Robot:Vision:DX/DY/DZ  (mm, TCP-local)
```

**`T_ee_cam`의 병진 성분은 1차적으로 상쇄된다** — 같은 카메라가 기준과 측정을
모두 찍기 때문이다. 회전 `R_ee_cam`만 정확하면 된다. 이것이 eye-in-hand 상대
측정이 절대 캘리브레이션 정확도에 둔감한 이유이고, `max_correction: 3.0` mm
같은 좁은 한계를 걸 수 있는 근거다.

> 이 성질은 §5(지그 로컬라이제이션)에서는 성립하지 않는다. 거기서는 절대
> `T_base_rack`이 필요하고 `T_ee_cam`의 병진 오차가 그대로 실린다. **그래서
> §4까지와 §5 이후는 요구 정확도가 다르다.**

---

## 3. Phase 0 — 측정 기반 (선행 필수)

이 단계가 끝나기 전에는 그 어떤 보정도 의미가 없다.

### 3.1 내부 파라미터 확보

**현재 얻을 수 없다.** IOC가 intrinsics를 PV로 내보내지 않는다:

```
RS405:cam1:RSFx_RBV   → Channel connect timed out: not found
RS405:cam1:RSDepthUnits_RBV → 0.0001      (이건 있음)
```

드라이버는 값을 갖고 있다 (`epics-rs-iocs/drivers/d435i/src/types.rs`에
intrinsics 타입 존재). 세 선택지:

| 안 | 방법 | 평가 |
|---|---|---|
| **A** | IOC에 `RSFx/RSFy/RSPpx/RSPpy/RSCoeff` PV 추가 | **권장.** 드라이버가 이미 보유. 변경 국소적. 장치 교체 시 자동 추종 |
| B | 비전 노드가 pyrealsense2로 직접 조회 | 카메라를 IOC가 배타 점유 중이라 충돌 |
| C | 체커보드로 독립 캘리브레이션 | 공장값보다 정확할 수 있으나 공수 큼. A 검증용으로 유용 |

**A로 진행하고, C를 1회 교차검증으로 쓴다.** 두 값이 크게 다르면 A를 믿지
않는다.

⚠ `dist_coeffs = zeros(5)`를 그대로 두지 말 것. D405가 왜곡 보정된 프레임을
주는지 실제 계수로 확인하고, 0이 아니면 반영한다.

### 3.2 태그 검출 파이프라인

```
RS405:image1:  ─(CA 또는 PVA)─►  비전 노드  ─► tag36h11 검출 ─► solvePnP
                                     │                              │
                                     └──────── Robot:Vision:* ◄─────┘
```

구현 언어는 Python (기존 `robot_gui`가 이미 pyepics 기반, `robot_gui` conda
env 재사용 가능). `pupil-apriltags` 또는 `cv2.aruco.DICT_APRILTAG_36h11`.

### 3.3 태그 크기 결정 — 시험띠로 실측

10 mm 태그가 실제로 검출되는지는 **계산이 아니라 측정으로** 정한다.
`doc/apriltags/`의 시험띠 (id 100–104, 10/15/20/25/30 mm)가 이 용도다.

개략 계산으로 예상되는 문제 (실측으로 확정할 것):

IOC의 실측 intrinsics(fx 393.284, cx 321.745, fy 392.673, cy 246.323)로
계산한 값이다. 사양서의 87°가 아니라 **78.3° × 62.8°** 이다:

```
HFOV = atan(cx/fx) + atan((640-cx)/fx) = 39.28° + 38.98° = 78.3°
VFOV = atan(cy/fy) + atan((480-cy)/fy) = 32.09° + 30.75° = 62.8°

640×480, 작업거리 150 mm
→ 시야 폭 = 150·(tan39.28° + tan38.98°) ≈ 244 mm → 0.38 mm/px
→ 10 mm 태그 ≈ 26 px
```

tag36h11은 테두리 포함 10×10 셀이라 26 px면 셀당 2.6 px — **경계선상**이다.
대응책 두 가지:

- **IOC 해상도를 1280×720으로 올린다** (st.d405.cmd:47이 지원 명시)
- 또는 더 큰 태그를 쓴다 (시험띠가 답을 준다)

실제로는 10 mm 태그를 붙일 자리가 없어 **100 mm 한 장을 바닥에 고정**했고,
작업거리 ≈ 290 mm에서 0.74 mm/px로 관측된다.

### Phase 0 완료 기준 (검증 가능)

- [ ] `caget RS405:cam1:RSFx_RBV` 등이 값을 반환한다
- [ ] 체커보드 독립 캘리브레이션 결과와 fx, fy가 **3% 이내** 일치
- [ ] 고정 태그를 고정 거리에서 300 프레임 관측 시 위치 표준편차
      **σ < 0.1 mm**, 검출 실패율 **0%**
- [ ] 시험띠로 "작업거리에서 안정 검출되는 최소 태그 크기"를 표로 확정

---

## 4. Phase 1 — hand-eye 캘리브레이션 (`T_ee_cam`), 평생 1회

### 4.1 절차 — 데몬의 `CalibMode = 3`

수집은 별도 도구가 아니라 **`robot-sequencer` 데몬 자체**가 한다. 수집
도구는 팔을 움직여야 하고, 로봇에 **쓰는** 경로는 하나뿐이다 — 프로그램
슬롯, RTDE 입력 레지스터, ur-driver의 되돌아오는 소켓. 별도 바이너리로
수집하려면 프로덕션 데몬을 내려야 하고 — 카메라를 보정하려고 그 카메라에
의존하는 데몬을 죽이는 것은 순서가 거꾸로다.

(초판은 "로봇은 RTDE 클라이언트를 하나만 받으므로"라고 적었는데 그건
틀렸다. 배타적인 것은 쓰기지 읽기가 아니다 — URControl 5.16은 RTDE
출력을 클라이언트별로 다중화한다. CLAUDE.md "그리퍼 통신" 앞 절에
경로별 실측/근거를 적어 뒀다. 결론은 같지만 이유가 다르고, 읽기 전용
감시는 공존한다.)

```bash
caput Robot:CalibMode 3        # Hand-Eye Calib
caput Robot:Trigger 1          # 1회차: aiming hold (jog 가능, 1 Hz 검출 로그)
# JogX/Y/Z로 태그를 화면 중앙에 맞춘다
caput Robot:Trigger 1          # 2회차: 수집 시작
```

트리거가 2회인 것은 다른 캘리브레이션 모드와 같은 이유다. idle 트리거
대기(`wait_for_trigger(false)`)는 jog를 서비스하지 않는다 — 그 자리는 티칭된
standby 자세이고 거기서 jog를 허용하면 시퀀스의 시작점이 움직인다. 조준은
모드가 정해진 뒤의 hold에서 한다. hold 중에는 검출기가 이미 떠 있으므로
1초마다 태그 위치를 로그로 되돌려준다 — "화면에 보인다"와 "검출기가 풀 수
있다"는 다른 주장이고, 수집을 성립시키는 것은 후자다.

바닥 고정 태그(**id 0, 100 mm**)를 브레드보드에 볼트 고정한다. 데몬은
2회차 트리거 시점의 자세를 home으로 잡고, 툴 자체 축(x/y/z) 둘레로 회전한
12자세를 돌며 각 자세에서:

1. 관절각 기록 → FK로 `T_base_ee`
2. 태그 관측 → solvePnP → `T_cam_tag`

자세마다 home으로 복귀하므로 검출 실패가 누적되지 않고, 모든 이동은
계획(RRT) 이동이 아니라 직선 보간 이동이고(§4.1 각주), 충돌 검사는
시퀀스와 같은 씬을 쓴다. 결과는
`handeye.out_dir/samples_<timestamp>.yaml` (캡처마다 새 이름).

**공전(orbit)이 아니라 제자리 회전인 이유.** `calibrateHandEye`가 원하는
것은 회전 다양성이지 병진이 아니고, 셀이 좁다. 290 mm에서 100 mm 태그는
78°×63° 시야 안에서 약 ±10°만 차지하므로 툴은 태그가 프레임을 벗어나기
전까지 수십 도를 돌 수 있다 — 그리고 툴 회전은 카메라를 마운트 오프셋
만큼(수십 mm) 옮길 뿐이어서, 같은 각도의 공전이 요구하는 ~100 mm 이동과
비교가 안 된다.

수집 자세 수(12) × 3축은 고정이고, 각도만 `handeye.angle_deg`로 조절한다.
축이 3개인 것은 필수다 — 회전축을 공유하는 두 상대운동은 AX = XB에서
축퇴(degenerate)이고, 이것이 "그럴듯한 오답"이 나오는 전형적 경로다.

```python
# eye-in-hand: 반환값이 곧 T_ee_cam
R_cam2gripper, t_cam2gripper = cv2.calibrateHandEye(
    R_gripper2base, t_gripper2base,     # invert 하지 않는다
    R_target2cam,   t_target2cam,
    method=cv2.CALIB_HAND_EYE_TSAI)
```

⚠ **`invert_gripper2base = False`.** 구 코드의 이 플래그는 eye-to-hand용이다
(`hand_eye_calibration_node.py:463`). eye-in-hand에서 켜면 결과가 조용히
틀린다 — 수렴은 하되 값이 틀리므로 residual만으로는 못 잡는다.

**회전 다양성이 정확도를 지배한다.** 위치만 옮기고 자세를 안 바꾸면
`calibrateHandEye`는 병조건이 된다. 태그를 화면 중앙에 맞춰 놓으면 이 셀
에서도 ±29°/±21°까지는 실측으로 확보된다.

> 여기서 §0.1의 level-tool 제약(`scene.rs:49`, ±3°)이 걸린다. 캘리브레이션
> 자세는 정확히 그 제약이 금지하는 툴 회전이다. 이 문서는 원래
> `Motion::suspend_level_tool`이 돌려주는 가드로 수집 동안만 제약을 끄는
> 설계를 적었으나, **그 함수는 구현되지 않았다.** 실제로 만들어진 것은
> 제약을 끄지 않고 아예 지나가지 않는 쪽이다: 제약은 `Motion::move_planned`
> 에서만 읽히고 수집의 모든 이동은 `move_direct`(직선 보간, 충돌 검사는
> 동일 씬)라 애초에 평가되지 않는다. 끄고 켜는 상태가 없으니 복원 누락도
> 없다.
>
> 대신 이 설계가 옮겨 놓은 위험은 다른 곳에 있었다. 제약을 지나가는 것은
> 수집 중의 이동이지 **수집이 끝난 뒤의 팔**이 아니다. 조준 자세는 level에서
> 수십 도(실측 70.8°) 벗어나 있고, 초기 구현은 팔을 거기 둔 채 트리거 대기로
> 돌아갔다 — 다음 시퀀스의 step 1이 `start or goal state is itself invalid`로
> 계획에 실패하고 데몬이 종료한다. `Sequence::handeye_return`이 모드 진입
> 자세로 되돌리는 것으로 닫혔고, `move_planned`은 시작 자세를 자기가 계획할
> 제약으로 먼저 판정해 다른 경로로 비-level이 된 경우도 이름을 대게 했다.

### 4.2 검증 — residual만 믿지 않는다

`calibrateHandEye`는 틀린 입력에도 답을 낸다. **독립 검증**이 필수다.
`tools/handeye/solve.py`가 이 둘을 자동으로 낸다:

- 여러 방법(Tsai / Park / Horaud / Daniilidis) 결과가 서로 **2 mm, 1° 이내**
  로 일치하는지 — 흩어지면 데이터가 나쁜 것이다
- leave-one-out: 한 자세를 빼고 적합한 뒤, 뺀 자세로 `T_base_tag`를 예측해
  나머지의 평균과 비교. 적합에 쓴 자세의 residual과 달리 이것은 실제
  측정이 지게 될 오차다

4점 태그의 reprojection error는 **정확도 지표가 아니다** — 미지수와 관측
수가 거의 같아 언제나 작게 나온다.

### Phase 1 완료 기준

- [ ] 검증셋 5자세에서 예측-실측 위치 오차 **< 2 mm**, 회전 오차 **< 1°**
- [ ] 4개 방법의 해가 서로 2 mm / 1° 이내
- [ ] `T_ee_cam`을 YAML로 저장 + 측정 일자·자세 수·residual 기록
- [ ] URDF에 카메라 링크 추가 (측정된 `T_ee_cam`으로) — scene/충돌 검사에서
      카메라 몸체가 고려되도록

---

## 5. Phase 2 — 관찰 모드 (이동 없음)

**코드 변경 없이** 이미 가능하다. `config.rs:196`의 `observe_only`가 정확히
이것이다 — 4개 훅에서 측정하고 로그만 남기며, 이동도 정지도 하지 않는다.

```yaml
vision:
  enabled: true
  observe_only: true      # 측정만
```

기존 시퀀스를 N회 돌리며 8개 측정 지점의 분포를 모은다.

### Phase 2 완료 기준

- [ ] 20 사이클 무중단, 검출 실패 0
- [ ] 8지점 각각에서 |d| 분포의 σ **< 0.2 mm**
- [ ] 반복 측정 편차가 `min_correction: 0.10` mm보다 크고
      `max_correction: 3.0` mm보다 충분히 작은지 확인 → 이 데이터로
      상한을 확정한다. 하한은 §14에서 이미 확정됐고, 여기서 다시 확인할
      것은 8지점 전부가 홀더 3 standby와 같은 재접근 편차를 갖는가다
- [ ] 이상치가 나온 지점·조명·자세를 기록

---

## 6. Phase 3 — 미세 보정 활성화

`observe_only: false`. 훅을 **한 번에 하나씩** 켠다:

```
pick_align → grip_offset → place_align → seating_check
```

각 단계에서 실패 시 즉시 이전 상태로 되돌린다. 실패 정의: 시퀀스 정지,
파지 실패, 안착 불량 중 하나라도 발생.

### Phase 3 완료 기준

- [ ] 훅 4개 전부 활성 상태로 50 사이클 무중단
- [ ] 보정 없이 돌린 대조군 대비 안착 실패율 감소를 수치로 제시
- [ ] `max_correction` 초과로 정지한 사례가 **전부 실제 이상**이었는지 확인
      (오검출로 인한 헛정지가 있으면 임계값 재조정)

---

## 7. Phase 4 — 지그 로컬라이제이션 → scene 갱신

여기서부터 **절대 정확도가 필요하다** (§2 각주). `T_ee_cam`의 병진 오차가
그대로 실리므로 Phase 1의 품질이 직접 드러난다.

### 7.1 구조

랙/측정 홀더의 10 mm 태그(id 1–11)를 관측해 `T_base_rack`을 구하고,
`SceneAsset.pose`에 주입한다.

**현재 갱신 경로가 없다.** `load_scene_assets`(`scene.rs:97`)는
`bringup.rs:46`의 connect 시점 전용이고, `ParryCollisionEnv`는
`scene_with_assets`(`scene.rs:126`)에서 매번 새로 만들어진다. 다행히
`SceneAsset.pose`가 단일 필드라 주입점 추가는 국소적이다.

### 7.2 안전장치 (문서 §5.3의 승인 흐름 유지)

```
Robot:RelocalizeReq=1 → 측정 3회 반복 → σ 검증
   → Robot:RelocalizeDelta 보고 (저장값 대비 이동량)
   → 한계 초과면 자동 거부
   → 운영자가 Robot:RelocalizeCommit=1 로 승인해야 반영
```

**자동 커밋 금지.** 태그 오검출로 잘못된 지그 위치를 커밋하면 다음 동작이
충돌이다.

### Phase 4 완료 기준

- [ ] 랙을 의도적으로 5 mm 옮긴 뒤 측정한 `RelocalizeDelta`가 실측 이동량과
      **1 mm 이내** 일치
- [ ] 3회 반복 측정 σ < 0.5 mm
- [ ] 오검출을 인위적으로 주입(태그 가림·오조명)했을 때 자동 거부가 동작
- [ ] scene 갱신 후 플래닝이 정상 동작 (기존 4개 티칭 포즈가 충돌로 읽히지
      않을 것 — **VHACD 근사가 이미 `holder1_on_position`을 충돌로 읽는
      기존 한계가 있으므로**, 갱신 전후 비교로 새 회귀만 판정한다)

---

## 8. Phase 5 — frame-relative 웨이포인트 (최대 위험, 선택)

`vision_inspection_plan.md` §5 그대로. **이 계획의 필수 경로가 아니다** —
Phase 3까지로 "카메라 보정"은 완성된다. Phase 5는 *재설치 대응*이 목적이다.

핵심 위험은 변하지 않았다: **IK 분지 선택.** UR3e는 한 포즈에 해가 최대 8개고
카메라는 어느 분지인지 말해주지 못한다. 기존 티칭 관절값을 seed로 유지해야
한다. `waypoint_mode: joint | frame_relative` fallback 필수.

---

## 9. 순서 요약과 의존성

```
Phase 0 (intrinsics + 검출 + 태그크기)   ← 선행 필수, 이것 없이는 전부 무의미
   │
Phase 1 (T_ee_cam, 1회)                  ← 회전 다양성이 품질을 지배
   │
   ├─► Phase 2 (관찰) ─► Phase 3 (보정 활성)   ★ "카메라 보정"의 완성점
   │
   └─► Phase 4 (scene 갱신) ─► Phase 5 (frame-relative, 선택)
```

Phase 3까지가 사용자가 요청한 "카메라로 보정"이다. Phase 4/5는 재설치
자동 대응이라는 **다른 목적**이며, 요구 정확도도 다르다 (§2 각주).

---

## 10. 즉시 착수 가능한 것 / 막혀 있는 것

| | 항목 | 상태 |
|---|---|---|
| ✅ | 바닥 100 mm 태그 볼트 고정 | 완료 (id 0) |
| ✅ | intrinsics PV 서빙 + 실측 (§3.1) | 완료 |
| ✅ | 검출 파이프라인 (`tools/handeye/detector.py`) | 완료, 재현성 검증됨 |
| ✅ | hand-eye 수집 (`CalibMode = 3`) + 해석 | 실행 완료. 해석은 `solve_joint.py`가 기준이고 `solve.py`는 교차검증용 (`doc/handeye_calibration.md`) |
| ✅ | `T_ee_cam` 확보 | `T_ee_cam.yaml`. run13 42자세 out-of-sample 검증, 재현성 0.101 mm |
| ✅ | 태그 시험띠 인쇄·부착 → 최소 크기 실측 | 지금 가능. 단 홀더에 태그를 못 붙이면 무의미해진다 |
| ✅ | IOC 해상도 1280×720 전환 시험 | 지금 가능 |
| ✅ | 무태그 특징 추출기 | 해소 (§12). 홀더를 인식하지 않는 쪽으로 풀렸다 — depth는 영역 게이트로, 정합은 기준 프레임 대비 차분으로 |
| ✅ | 비전 노드 구현 | `tools/vision/vision_node.py` (§15). Pick/Place Align을 재고 Grip Offset·Seating은 `Valid=0`으로 거절한다. 기준은 홀더 3·2·4까지 교시됨. 남은 것은 나머지 홀더와 Phase 2, 그리고 §15.6 |

---

## 11. 미확정 — 실측해야 정해지는 값

문서가 추정치로 적고 있으나 **아직 측정되지 않은** 것들.

- 작업거리에서 안정 검출되는 최소 태그 크기 (10 mm로 되는가) — 시험띠 미실행,
  현재는 100 mm 한 장으로 우회
- `max_correction`의 근거 있는 값 (현재 3.0 mm는 추정). `min_correction`은
  §14에서 실측으로 확정됐다
- ~~D405 최소 작업거리(사양 ~70 mm)와 티칭 `above` 자세의 실제 거리 관계~~
  실측·계산 완료 (`T_ee_cam` + 티칭 자세 FK): 카메라–파지점 광축 거리가
  `standby` 136.0 mm, `above` **63.3 mm**, `on_position` 62.2 mm.
  `above`는 D405 스테레오 최소거리 아래라 **깊이가 나오지 않는다**
  (모노 프레임은 별개 문제). `above_y_offset`이 −5 mm 툴 y = 수직
  방향이라 `on_position`과 광축 거리가 1.1 mm밖에 차이나지 않는 것이
  원인. 보정 관측은 `standby`에서 해야 하고, 거기서 Ø25.1 mm 특징이
  72 px로 잡힌다.
- 640×480 15 fps로 충분한지, 아니면 해상도·프레임률 상향이 필요한지
- ~~`min_correction`의 근거~~ → **확정, §14**. 프로덕션 사이클 20회로 재접근
  σ (0.022, 0.007) mm, p-p (0.095, 0.026) mm를 얻어 `0.10` mm로 올렸다.
  §12.3의 0.070 mm는 n=1이었고 20회 중 최대값(0.062 mm)보다도 크다.
  `max_correction: 3.0`은 여전히 추정 — 상한은 "얼마까지가 티칭 오차인가"를
  묻는 값이라 이 측정으로 답이 나오지 않는다

확정된 것(더는 추정이 아님):

- intrinsics: fx 393.284 / fy 392.673 / cx 321.745 / cy 246.323 → HFOV 78.3°
  (사양값 87°는 **틀렸다**)
- 왜곡 모델 규약: IOC가 보고하는 `BrownConradyInverse`는 **OpenCV 정방향
  Brown-Conrady와 같다**. 이름으로 추정하지 않고 `librealsense2.so`에 직접
  물었다 — 같은 계수로 `rs2_project_point_to_pixel`이 `cv2.projectPoints`를
  `RS2_DISTORTION_BROWN_CONRADY`에서 **정확히(0.0000 px)** 재현하고,
  `INVERSE_BROWN_CONRADY`에서는 **0.0223 px** 차이가 난다. 그 0.0223 px는
  librealsense가 INVERSE를 `MODIFIED_BROWN_CONRADY`와 **동일하게** 투영하기
  때문에 생기는 librealsense 내부 분기 차이지, OpenCV와의 규약 차이가 아니다
  (이전 판은 "접선항 적용 순서 차이"라고 적었으나 그건 측정된 바 없는
  추정이었다). "Inverse"는 OpenCV 기준이 아니라 `MODIFIED_BROWN_CONRADY`의
  역투영 기준 이름이다. 따라서 계수를 그대로 solvePnP에 넣는 것이 맞고,
  버리면 모서리에서 5.8 px = 290 mm에서 4.3 mm가 틀어진다.
  재현: `tools/handeye/check_distortion_model.py`
- 검출 재현성: 정지 태그 20회 연속 검출에서 σ = (0.015, 0.008, 0.056) mm,
  20/20 서로 다른 프레임. 단 이는 아래 두 버그를 고친 뒤의 값이다 —
  pyepics가 `use_monitor=False` 없이는 캐시를 돌려주는 문제, 그리고
  cv2 기본값 `CORNER_REFINE_NONE`이 코너를 정수 픽셀로 양자화하는 문제.
  둘 다 "완벽한 재현성"으로 위장하며, 그대로 뒀다면 `T_ee_cam`에 0.74 mm급
  오차가 조용히 실렸을 것이다.

---

## 12. 무태그 특징 추출 — 홀더를 인식하지 않는 쪽으로 (2026-08-14 실측)

§10이 마지막까지 ⛔로 남겨둔 항목이다. 막힌 이유는 "금속 홀더를 어떻게
인식하나"였고, 풀린 방식은 **인식하지 않는 것**이다. 보정에 필요한 것은
절대 포즈가 아니라 기준 대비 어긋남뿐이므로(§2), 문제를 물체 인식에서
영상 정합으로 바꾸면 정반사도 무태그도 장애물이 아니다 — 정반사는 모델
기반 검출을 깨뜨리지, 같은 자세에서 반복 촬영한 두 장의 상호상관을
깨뜨리지 않는다.

### 12.1 depth는 재는 데 못 쓰지만 가르는 데는 쓴다

standby에서 찍은 전체 프레임 depth 히스토그램:

```
   75 mm  16779 px   ← 홀더 스택
  150 mm    860 px
  ────────  없음  ────────  525 mm 폭의 공백
  675 mm    247 px
  825 mm+  .......  ← 배경 전부
```

50–250 mm 게이트가 프레임의 **6.23%(19145 px)만 남기고** 어수선한 배경을
통째로 지운다. 남는 이물은 프레임 우하단 모서리의 1505 px 한 덩어리뿐이고,
컬럼과 연결되지 않아 버려진다.

금속에서 depth가 1.83 mm 치우침·8.48 mm 산포였던 것이 여기서는 무해하다.
**재는 게 아니라 가르는 용도**이고 갈라야 할 간격이 525 mm다. 이 구분이
이 절 전체의 요지다 — depth의 실패는 metrology로서의 실패였지 segmentation
으로서의 실패가 아니었다.

### 12.2 "빈 부분은 어둡다"는 이 하드웨어에서 성립하지 않는다

보어가 광 트랩이라 어둡게 잡힐 것이라는 기대는 **실측으로 기각**된다.
depth ROI 안 mono는 24979 px, 중앙값 124이고 80 미만이 1890 px(7.6%),
60 미만이 398 px(1.6%)다. 60 미만으로 잡히는 것은 퍽 림과 시트가 만나는
그림자 호뿐이고 홀더당 100–250 px짜리 얇은 초승달이다. 실험실이 확산광으로
밝고, 이 홀더는 카메라 쪽으로 깊은 공동을 내주지 않는다.

따라서 "빈 부분"의 판별자는 **밝기가 아니라 거리**여야 한다. 12.1이 그것이다.

### 12.3 추정기의 잡음 바닥과, 그보다 40배 큰 것

팔을 홀더 3 standby에 세워둔 채 20프레임, ROI는 12.1의 게이트,
정합은 `cv2.findTransformECC(MOTION_TRANSLATION)`:

```
게이트 면적       4697 px, σ 79 px (1.7%)
ECC 병진 σ        (0.0050, 0.0036) px = (0.0017, 0.0012) mm
        p-p       (0.022, 0.014) px
```

이 숫자가 위장이 아닌지 따로 확인했다 — 이 저장소에서 "완벽한 재현성"은
이미 두 번(pyepics 캐시, `CORNER_REFINE_NONE`) 버그의 가면이었다.
ArrayCounter가 2씩 전진해 전부 다르고, 창 안 픽셀의 75%가 프레임마다
바뀌며, 화소별 시간 σ는 1.41 DN이다. 잡음은 실재하고 추정기가 4700 px에
걸쳐 평균해서 이긴다: 1.41 DN / (5 DN/px × √4700) ≈ 0.004 px로, 실측
0.005 px와 맞는다.

**그런데 지배하는 것은 센서가 아니라 팔이다.** 같은 자세를 떠났다가
(standby → above → retreat → 계획 이동) 돌아와 다시 찍은 프레임은
기준 대비 **0.070 mm**(dx 0.013, dy 0.069, ECC 상관 0.980) 어긋나 있었다.
n = 1이라 σ가 아니라 한 번의 차이지만, 잡음 바닥의 40배다. 데드밴드가
걸러야 할 대상이 무엇인지가 이 측정으로 바뀌었다. (n을 20으로 늘린 결과는
§14. 0.070 mm는 20회 중 어느 값보다도 컸다 — 크기는 틀렸고, 결론은 맞았다.)

### 12.4 훅이 걸린 자세에서는 대상이 보이지 않는다

`sequence.rs:236-238`은 step 2(`holder_above`)를 끝낸 직후 측정한다.
홀더 3의 `above`에서 실제로 찍어 확인한 결과:

- 파지점(`on_position`, `above_y_offset` −5 mm 만큼 툴 +y)은
  **(337, 535)** 에 투영된다 — 480행짜리 프레임의 아래 모서리보다 **56행 아래**.
  ee 원점조차 (337, 508)로 프레임 밖이다.
- 그 거리에서 프레임이 덮는 툴 y 범위는 −41 mm ~ −3.7 mm, 즉 대상의
  **위쪽 3.7–41 mm** 다. 홀더 피치가 30 mm이므로 화면 중앙을 채우는 원반은
  **한 칸 위 홀더의 퍽**이다 — 홀더 3의 `above`에서 실제로 보이는 것은
  홀더 2이고, 투영 (335, 363)이 그 원반 위에 정확히 떨어진다.
- depth도 없다. 유효 화소가 69% → 51%로 떨어지고, 근거리 클러스터가
  사라지며(75 mm 빈 16779 → 300 px), 10072 px가 0–75 mm — 스테레오 하한
  아래다. 50–250 mm 게이트는 최대 성분이 34.3%인 얼룩이 되고 그 성분은
  **뒤쪽 벽** 위에 있다. 게이트가 약해지는 정도가 아니라 틀린 답을 준다.

"보이지 않는다"보다 나쁘다. 소박한 검출기라면 이웃 홀더에 확신을 갖고
붙어 엉뚱한 보정을 낼 것이다. 훅은 **standby로 옮겨야** 한다 — 광축 거리
136.0 mm, Ø25.1 mm 특징이 72 px, 12.1–12.3의 숫자가 전부 그 자세의 것이다.

→ 옮겼다. §13.

### 12.5 옮기기 전에 고쳐야 할 것 — `above`에서는 계획 이동이 안 된다

위 촬영을 하려고 팔을 `above`에 세워둔 김에 드러난 것이다.
`above`에서 출발하는 `move_planned`는

```
holder_standby: planning failed: planner 'rrt_connect' failed:
  planning failed: start or goal state is itself invalid
```

로 실패한다. §4.1의 level-tool 가드는 통과했으므로(그랬다면 그 이름을
댔을 것이다) 제약 문제가 아니라 상태 유효성 문제다. 정상 시퀀스가 이걸
못 만난 이유는 **계획 이동이 `above`에서 출발한 적이 없기 때문**이다 —
계획 이동은 1/7/18뿐이고 각각 standby·retreat·sh_standby에서 출발하며,
above↔on은 전부 cartesian이다. 빠져나온 경로도 시퀀스 자신의 것이었다:
step 6(`above`→`retreat`, cartesian) 뒤 step 18(계획 이동 → standby, 0.09 s).

훅을 어디에 두든, 그리고 관측을 위해 어떤 자세에 잠깐 머무르든, 그 자세에서
복귀가 가능한지가 선행 조건이다.

### 12.6 이 복구 과정이 드러낸 운영상 결함 셋

전부 이번 한 번의 촬영에서 실제로 겪었다.

1. **계획 실패가 데몬을 죽인다.** 팔은 멀쩡히 서 있는데 데몬이 나가고
   RTDE 연결이 끊긴다. hand-eye 수집 실패는 이미 데몬을 죽이지 않도록
   고쳐져 있다(`doc/handeye_calibration.md`) — 같은 처리가 시퀀스 쪽에는
   없다.
2. **재시작이 그리퍼를 여닫는다.** 기동 로그의 "Hand-E successfully
   activated"는 Robotiq 활성화 스트로크다. 시료를 문 채 데몬이 죽으면
   재시작이 그것을 떨어뜨린다. 활성화는 이미 활성인 그리퍼에 대해
   멱등이어야 한다.
3. **PauseStep은 앞으로만 풀린다.** `wait_for_pause_step_change`에서
   빠져나오는 길은 다음 스텝으로 진행하는 것뿐이라, "여기서 멈추고
   standby로 돌아가라"를 표현할 수단이 없다. 그래서 이번에도 데몬을
   두 번 죽여야 했고, 그때마다 2번 위험을 무릅썼다.

셋은 한 사건의 세 얼굴이다: **중단 상태에서 안전 자세로 돌아가는 소유자가
없다.** 3이 없어서 죽여야 하고, 1이 죽이고, 2가 죽는 것을 위험하게 만든다.

---

## 13. 훅을 standby로 옮김 (2026-08-14, 12.4의 해소)

12.4가 남긴 작업을 실행했다. 옮기기 전에 12.5의 선행 조건 — "그 자세에서
복귀가 가능한가" — 는 `CalibMode = 4` 복구 모드로 해소됐고, 12.6의 결함
1·3도 같이 닫혔다(2는 열려 있다).

### 13.1 어디서 보이는지를 먼저 계산했다

12.4는 홀더 3 하나를 실제로 찍어서 얻은 결과다. 옮길 곳이 모든 홀더와
샘플홀더에서도 성립하는지는 사진이 아니라 모델로 확인했다 — URDF FK로
자세를 만들고 `T_ee_cam` + 내부 파라미터로 투영한다. 검증은 12.4의 실측과
맞는지로 했다: 계산이 `above`에서 (336, 535), 축상 63.3 mm를 내놓았고
실측은 (337, 535)였다. standby도 계산 136.5 mm / 73 px 대 실측 136.0 mm /
72 px.

| 관측 자세 | 파지점 투영 | 축상 거리 | 광축각 | 25.1 mm = ? |
|---|---|---|---|---|
| 홀더 `above` (기존) | (336, **535**) | 63.3 mm | 35.3° | 프레임 밖 |
| 홀더 `standby` | (306, 330) | 136.8 mm | 11.2° | 73 px |
| 샘플홀더 `sh_standby` | (313, 277) | 208.8 mm | 3.7° | 48 px |

샘플홀더 쪽이 오히려 화면 중앙에 가깝다. 대신 1.5배 멀어 mm/px가 0.343 →
0.523으로 커지므로, 12.3의 ECC 잡음 바닥 0.0017 mm는 그쪽에서 0.0027 mm가
된다. 팔의 재접근 편차(0.070 mm)에 여전히 25배 눌린다.

`the_hooks_observe_from_poses_that_see_the_target`(model.rs)가 이 표를
테스트로 고정한다. 홀더 1·3·10과 샘플홀더에 대해 standby에서는 프레임 안,
`above`에서는 프레임 밖임을 함께 주장한다 — 뒤쪽 주장이 없으면 훅이 조용히
되돌아갈 수 있다.

### 13.2 파지 편차(Grip Offset)만은 옮겨도 소용없다

물린 퍽은 툴에 고정돼 있어서 팔이 어디에 서 있든 카메라와의 관계가
같다. 퍽 중심은 (336, **509**) — 프레임 아래 29행 밖이다. 다만 완전히 안
보이지는 않는다: 반경 12.55 mm 원반의 가까운 쪽 림이 (335, **405**)로
프레임 안에 들어온다. 즉 화면 맨 아래에 초승달만 걸린다.

광축에서 33°, 왜곡 모델이 가장 덜 구속된 가장자리다. 여기서 측정이
가능한지는 **재본 적이 없다** — 그래서 훅을 지우지도, 옮기지도 않고 원래
자리(스텝 5/16)에 뒀다. 자세를 바꿔도 그림이 같으므로 옮길 이유가 없다.
이 훅을 쓰려면 초승달 정합을 실측하거나, 카메라를 다시 앉혀야 한다.

### 13.3 보정량이 프레임을 달고 다니게 했다

측정 자세와 적용 자세가 달라지면서 `[f64; 3]` 세 숫자만으로는 어느 툴
프레임의 것인지 말할 수 없게 됐다. `Correction { d, frame }`이 관측 자세의
자세(quaternion)를 함께 들고 다니고, `corrected`가 적용 대상 자세의
프레임으로 회전시킨다. `combine_corrections`도 두 항(슬롯 정렬 = standby,
파지 편차 = above)을 공통 프레임으로 옮긴 뒤 더한다 — 서로 다른 프레임의
벡터를 더하던 자리다.

실제 회전량은 랙 0.79°, 샘플홀더 0.21°다. 3 mm 상한에서 41 µm이라 무시해도
당장은 티가 안 난다. 회전을 넣은 이유는 크기가 아니라, standby를 다시
티칭했을 때 조용히 틀리지 않게 하기 위해서다.

### 13.4 딸려 나온 단순화

하강 스텝(3/9/14/20)의 via 경유가 사라졌다. 기존에는 `above`에서 재고
`above`를 고쳤으니 옆으로 옮긴 뒤 내려가야 했다 — `cartesian_via`가 그
때문에 있었다. 이제 보정이 `above`로 가는 이동에 흡수되므로 하강은 다시
순수 수직이고, `cartesian_via`는 `cartesian`으로 접혔다.

스텝 번호는 하나도 바뀌지 않았다(재개 절차와 GUI 호환). 바뀐 것은 측정이
걸리는 자리뿐이다:

| 훅 | 이전 | 이후 |
|----|---|---|
| Pick Align | 스텝 2·13 후 (above) | 스텝 1·12 후 (standby) |
| Place Align | 스텝 8·19 후 (above) | 스텝 7·18 후 (standby) |
| Grip Offset | 스텝 5·16 후 | 그대로 (13.2) |
| Seating | 스텝 11·22 후 (above) | 스텝 12·23 후 (standby) |

---

## 14. 재접근 편차 n=20 — 데드밴드가 걸러야 할 크기 (2026-08-15 실측)

§12.3은 팔의 재접근 편차를 **한 번** 쟀다(0.070 mm). 그 한 번으로 데드밴드를
정할 수는 없어서, 프로덕션 사이클 20회를 돌려 분포를 얻었다.
도구는 `tools/vision/reapproach.py`.

### 14.1 어떻게 20번 떠나고 돌아오게 했는가

팔을 움직일 수 있는 것은 시퀀서 데몬뿐이다. 그래서 별도 경로를 만들지 않고
운전자가 하는 그대로 `Robot:Trigger`로 몰았다. 측정이 가능한 이유는
`PauseStep` 하나다 — `step_epilogue`가 `CurrentStep`을 쓴 **뒤** `PauseStep`이
같은 값인 동안 멈춰 서므로, 관측 자세에서 팔이 정지한 채로 프레임을 받을
시간이 생긴다. 해제는 그 런이 다시 만나지 않을 값을 쓰는 것이고, 0은 홀드를
아예 끄므로(`wait_for_pause_step_change`가 0에서 즉시 반환) 해제값이자
평상값이다.

`Wait`는 트리거 전에 미리 답해 둘 수 없다. `run_sequence`가 매 런 첫머리에
`write_wait(0)`으로 지운다(sequence.rs:201). 그래서 스텝 12에서 `Loaded`가
서는 것을 보고 그때 답한다 — 측정 프로그램이 하는 것과 같은 악수다. 이걸
알기 전 첫 시도는 스텝 12에서 10분간 서 있었다.

사이클 실체 시간은 **21.2 s**(스텝 0–12 10.6 s, 13–23 11 s)다. 20회에 7분.

첫 시도의 첫 샘플은 버렸다. 팔이 이미 standby에 있으면 스텝 1의 계획 이동은
69 ms짜리 무이동이라, 그 프레임은 재접근이 아니라 정지 샘플이다.

### 14.2 숫자

기준 프레임 1장에 20 사이클의 스텝 1 도착을 각각 정합했다. ROI·게이트·정합기는
§12.1/§12.3과 같다.

```
정지 잡음 바닥 (20프레임, 대조군)  σ (0.0010, 0.0009) mm     ← §12.3은 (0.0017, 0.0012)
재접근 (20사이클)                  σ (0.0222, 0.0074) mm
                                   p-p (0.0952, 0.0259) mm
                                   |d| 평균 0.0202, 최대 0.0619 mm
```

세 가지가 읽힌다.

- **x가 y의 3배다.** 랙을 따라가는 축이 물려 들어오는 축보다 덜 재현된다.
- **§12.3의 0.070 mm는 20회 중 어느 값보다도 컸다.** n=1이 컸던 쪽으로
  치우친 표본이었다는 뜻이고, 그 값으로 임계값을 정했으면 과했을 것이다.
  다만 §12.3의 결론(데드밴드가 거를 대상은 센서가 아니라 팔)은 그대로다 —
  재접근 편차는 잡음 바닥의 **20배**다.
- **ECC 상관이 0.9981에서 0.9723으로 단조 감소했다.** 사이클마다 조금씩
  달라지는 것이 있다는 뜻이고, 퍽이 매번 미세하게 다른 회전으로 안착하는
  것이 가장 그럴듯하다. 저장된 프레임을 기준으로 쓰면 20 사이클 규모에서
  기준이 낡는다 — 비전 노드가 프레임이 아니라 모델을 기준으로 삼아야 할
  이유가 하나 더 생겼다.

### 14.3 `min_correction` = 0.10 mm

관측 자세가 20회에 걸쳐 p-p 0.095 mm(x)만큼 흔들린다면, 그보다 작은 보정은
팔이 자기 재현성을 쫓는 것이다. 0.10 mm는 그 위에 있다. 종전 0.05 mm는 분포
**안에** 있었고 — 20회 중 1회가 넘었다 — 그만큼 헛보정이 나갔을 것이다.

바꾼 곳: `config/sequencer.yaml`, `config/sequencer_nostage.yaml`,
`VisionConfig::default()`.

측정하지 않은 것: 나머지 7개 훅 지점. 이 20회는 홀더 3의 pick@rack
관측(스텝 1) 하나다. 샘플홀더 쪽 standby와 파지 편차 자세는 팔의 자세가
달라 재접근 편차도 다를 수 있고, Phase 2가 8지점 전부를 도는 이유가 그것이다.

---

## 15. 비전 노드 (2026-08-15)

§10이 마지막까지 ⛔로 남겨둔 항목. `tools/vision/vision_node.py`.

계약은 새로 정하지 않았다 — `vision_sim.rs`가 리허설용으로 이미 구현해 둔
것이 계약이다. `Req`가 바뀌면 `Kind`를 읽고, 페이로드를 먼저 쓰고 `Done`을
**맨 마지막에** 쓴다(시퀀서는 `Done` 에코를 "결과 준비됨"으로 읽는다).
기동 시 `Done`에서 출발해 재시작 후 남아 있는 `Req`를 새 요청으로 오인하지
않는다.

### 15.1 무엇을 재고, 무엇을 재지 않는가

| Kind | 스텝 | 이 노드 |
|---|---|---|
| 1 Pick Align | 1, 12 | **잰다** |
| 3 Place Align | 7, 18 | **잰다** |
| 2 Grip Offset | 5, 16 | `Valid=0` — 안 잰다 (§13.2) |
| 4 Seating | 12, 23 | `Valid=0` — 안 잰다 (§12.1) |

안 재는 종류에 **0을 답하지 않는다.** 0은 "완벽히 정렬됨"·"안착됨"으로
읽히고 데드밴드를 그냥 통과하며, 진짜 답과 구별되지 않는다. `Valid=0`은
시퀀스를 세우는데 그게 올바른 실패다. `sequencer.yaml`에서 두 훅을 껐다 —
노드가 답할 수 없는 훅을 켜 두는 것은 설정이 사실과 어긋난 상태다.

`Kind`만으로는 부족하다. Pick Align은 스텝 1과 12에서, Place Align은 7과
18에서 각각 한 번씩 뜨는데 장면이 서로 다르다. 그래서 기준을
`(Kind, CurrentStep)`으로, 랙 쪽 두 자세(1·18)는 `Holder`까지 붙여
키를 만든다. 요청 시점에 `CurrentStep`은 이미 그 값이다 — `step_epilogue`가
이동 완료 후에 쓰고 그 다음에 훅이 걸린다.

### 15.2 기하

영상면에서 `(du, dv)` px 움직인 특징은 카메라 프레임에서

```
d_cam = (du·Z/fx,  dv·Z/fy,  0)
d_ee  = R_ee_cam · d_cam
```

`Z`는 게이트 안 depth의 중앙값이다. §12.1이 이 금속에서 depth를 metrology로
쓸 수 없다고 했지만 여기서 depth는 **측정값이 아니라 배율**이다. 8 mm
오차는 136 mm에서 6%이고, 시퀀서가 받아들이는 최대 보정 3 mm에 0.18 mm로
실린다.

세 번째 성분이 0인 것은 "툴 z 방향으로 안 움직인다"가 아니라 **광축 방향은
이 노드가 재지 않는다**는 뜻이다. `R_ee_cam`이 12.4° 기울어 있어 `d_ee`의
세 성분은 일반적으로 모두 0이 아니다 — 실측 확인: 정지 상태 probe에서
`dz`가 `dy`와 같은 크기로 따라 나온다.

intrinsics는 IOC 것이 아니라 `T_ee_cam.yaml` 안의 것을 쓴다. hand-eye
동시해가 렌즈 모델을 함께 정제했고, `R_ee_cam`은 그 모델 아래에서만 맞는다.

### 15.3 창을 손으로 잡지 않는다

`reapproach.py`는 홀더 3 standby 전용으로 창을 손으로 잡았다(285:380,
260:360). 노드는 그럴 수 없다 — 관측 자세가 넷이고 홀더가 열이다. 대신
게이트의 **최대 연결성분**을 잡고 그 바운딩박스에 24 px 여유를 준다.
§12.1이 본 프레임 우하단 1505 px 이물이 이 단계에서 떨어진다.

실측(홀더 3 standby): 창 (116,480,239,375), 게이트 17585 px, 거리 132.7 mm.
§11이 계산으로 낸 standby 광축거리 136.0 mm와 맞는다(게이트 중앙값은 파지점이
아니라 스택 앞면이라 조금 짧다).

### 15.4 검증

정지 상태 왕복(팔이 안 움직였으므로 0이 나와야 한다):

```
probe  dx=+0.0001 dy=-0.0017 dz=+0.0004 mm, ECC 0.9997
probe  dx=-0.0015 dy=-0.0011 dz=+0.0004 mm, ECC 0.9997
```

핸드셰이크 4종을 `caput`으로 직접 몰아 확인했다. 응답 시간은 최대 0.49 s로
`vision.timeout: 2.0`의 1/4이다.

```
Kind 1 (기준 있음)  Valid=1  DX=+0.00032 DY=-0.00195 DZ=+0.00040  Q=0.9997  0.49s
Kind 2 GripOffset   Valid=0  0/0/0                                Q=0       0.09s
Kind 3 (기준 없음)  Valid=0  "no reference taught for k3_s0"      Q=0       0.09s
Kind 4 Seating      Valid=0  Seated=0                             Q=0       0.09s
```

### 15.5 기준 교시 (홀더 3, 4/4)

기준은 실제 런이 마주치는 상태에서 떠야 한다. 네 자세의 장면이 서로 다르다 —
스텝 1은 랙에 퍽이 있고, 7은 샘플홀더가 **비어** 있고(퍽은 손가락에),
12는 샘플홀더에 퍽이 있고, 18은 랙이 **비어** 있다. 그래서 한 사이클을
돌면서 네 홀드에서 각각 뜬다(`teach-run`).

| 키 | 스텝 | 창 | 게이트 | 거리 |
|---|---|---|---|---|
| `k1_s1_h3` | 1 | (116,480,233,375) | 17543 px | 132.5 mm |
| `k3_s7` | 7 | (253,480,237,467) | 14525 px | 201.7 mm |
| `k1_s12` | 12 | (229,480,247,389) | 15362 px | 205.4 mm |
| `k3_s18_h3` | 18 | (116,480,237,458) | 18417 px | 126.5 mm |

샘플홀더 쪽 두 자세가 ~205 mm로 게이트 상한 250 mm에 랙 쪽보다 훨씬
가깝다. 지금은 여유가 있지만 게이트를 좁힐 때 걸리는 것은 여기다.

교시는 자기 자신에 대고 하는 것이라 항상 성공한다. 값이 있는지는 한 사이클
뒤에 같은 네 자세에서 답을 받아 봐야 안다(`check-run`):

```
스텝  1  |d| 0.0043 mm  ECC 0.9996
스텝  7  |d| 0.0029 mm  ECC 0.9997
스텝 12  |d| 0.0112 mm  ECC 0.9996
스텝 18  |d| 0.0314 mm  ECC 0.9993
```

넷 다 `min_correction: 0.10` mm 아래이고 §14의 재접근 σ 0.022 mm와
같은 크기다 — 기준이 하루 지난 게 아니라 한 사이클 지난 상태에서 나올 수
있는 최선이다. 스텝 18이 가장 큰 것도 §14와 일치한다(랙 쪽 자세).

### 15.6 홀더 2·4 교시, 그리고 거기서 드러난 것

홀더를 바꿔 `teach-run`을 두 번 더 돌렸다. 교시는 이제 **덧쓰지 않는다** —
두 번째 홀더의 사이클도 스텝 7·12를 지나가는데 그 둘은 홀더에 무관한 키라,
그대로 두면 홀더 3에서 떠서 `check-run`까지 통과한 기준을 아무 이득 없이
갈아치운다. 이미 있는 기준은 유지하고 `--force`로만 교체한다.

| 키 | 스텝 | 창 | 게이트 | 거리 |
|---|---|---|---|---|
| `k1_s1_h2` | 1 | (187,480,243,373) | 14045 px | 132.8 mm |
| `k3_s18_h2` | 18 | (187,480,237,472) | 14537 px | 132.7 mm |
| `k1_s1_h4` | 1 | (29,318,236,375) | 10933 px | 123.3 mm |
| `k3_s18_h4` | 18 | (31,480,235,427) | 19897 px | 124.1 mm |

창의 세로 위치가 홀더 번호를 따라간다(h2 y0=187, h3 116, h4 29 — 한 칸당
70~87 px, 30 mm 간격의 투영과 맞는다). 홀더 4의 스텝 1 성분만 프레임
아래쪽까지 닿지 않아 10933 px로 가장 작지만 `MIN_GATE_PX`의 20배다.

`check-run` 8회분(각각 교시 다음 사이클):

| 스텝 | 홀더 2 | 홀더 4 |
|---|---|---|
| 1 | 0.0214 mm, ECC 0.9976 | 0.0257 mm, ECC 0.9969 |
| 7 | 0.0339 mm, ECC 0.9982 | **0.1744 mm**, ECC 0.9953 |
| 12 | 0.0172 mm, ECC 0.9987 | 0.0405 mm, ECC 0.9982 |
| 18 | 0.0436 mm, ECC 0.9993 | 0.0258 mm, ECC 0.9993 |

굵은 값 하나가 `min_correction: 0.10` mm를 넘는다. 잡음이 아니다 — ECC
0.9953이면 같은 장면이고, `k3_s7` 하나만 놓고 세 사이클을 보면 퍽을 어느
홀더에서 집어 왔느냐에 따라 0.0029(h3) → 0.0339(h2) → 0.1744(h4) mm로
움직인다. §14의 재접근 σ 0.022 mm보다 한 자릿수 크다.

원인은 ROI에 있다. `target_crop`은 깊이 게이트의 최대 연결성분을 잡는데,
PlaceAlign 두 자세(7·18)에서는 **손가락에 물린 퍽**이 표적보다 더 가까이
있으면서 화면에서 표적 성분과 붙어 하나로 잡힌다(`s7_ref`, `k3_s18_h4_ref`
오버레이에서 아래쪽 큰 원반이 그것). 그래서 ECC가 세계 고정 표적과 툴 고정
물체를 섞어서 잰다. 이 둘은 보정 부호가 반대다:

- 표적이 +d 움직였다 → 툴을 +d 옮기는 것이 맞다.
- 퍽이 툴 안에서 +d 어긋나 물렸다 → 툴을 **−d** 옮겨야 퍽이 제자리에 간다.

섞인 답은 두 성분의 텍스처 비율로 가중된 값이고, 그 비율은 아무도 정하지
않았다. 스텝 12가 이 문제에서 자유로운 이유도 같다 — 거기서는 퍽이 이미
샘플홀더에 놓여 세계 고정이다(0.0112/0.0172/0.0405 mm의 증가는 놓인 위치가
실제로 달랐다는 뜻이고, 그건 재야 할 값이다).

지켜야 할 불변식은 **ROI는 세계 고정 기하만 포함한다**이고, §15.6까지는
그것이 "가장 큰 성분"이라는 규칙에 우연히 맡겨져 있었다. 연결성분으로는
가를 수 없다 — 물린 퍽과 표적은 화면에서 붙어 하나의 성분이다. 가르는
축은 깊이뿐이다.

### 15.7 게이트의 근거리 경계로 닫았다

교시된 네 자세의 깊이 분포를 보면 두 무리가 완전히 갈라져 있다:

| 자세 | 물린 퍽 | 세계 고정 | 사이 |
|---|---|---|---|
| 스텝 7 | 50–69.1 mm (4723 px) | 190.3 mm부터 | 비어 있음 |
| 스텝 18 | 50–75.6 mm (3253 px) | 109.5 mm부터 | 80–105 mm에 0 px |
| 스텝 1 | 없음 (그리퍼 빈손) | 110.5 mm부터 | — |
| 스텝 12 | 없음 | 190.1 mm부터 | — |

그래서 `DEFAULT_GATE`의 근거리 경계를 0.050 → **0.090 m**로 올렸다. 퍽의
원거리 끝(75.6 mm)에서 14 mm 위, 세계 고정의 근거리 끝(109.5 mm)에서
19 mm 아래 — 34 mm 빈 띠의 가운데다. 게이트는 창(교시)과 마스크(관측)를
둘 다 만드는 유일한 입력이라, 한 값이 두 경로를 같이 닫는다. 스텝별 분기가
없다는 점이 요점이다: 물린 것이 없는 스텝 1·12에서는 저절로 무작동이다
(교시된 프레임으로 확인 — 창이 글자 그대로 동일했다).

게이트는 기준마다 npz에 저장되므로 옛 기준이 새 규칙으로 조용히
재해석되지는 않는다. 대신 옛 기준 8개는 전부 다시 떴다. `reapproach.py`도
같은 상수를 기본값으로 쓰지만 §14 캠페인의 자세는 빈손이고 표적이 136 mm라
경계 이동이 닿지 않으며, 그 캠페인의 npz에는 자기 게이트가 박혀 있어
`stats` 재현도 그대로다.

**교시는 한 사이클을 쓴다.** 그래서 이제 창뿐 아니라 전체 프레임과 깊이
맵도 npz에 함께 넣는다. 이번처럼 규칙이 바뀌면 팔을 다시 돌리는 대신 이미
뜬 프레임에서 창을 다시 뽑아 검증할 수 있다 — 위 표와 "창이 동일하다"는
확인이 전부 로봇 없이 나왔다.

검증은 `check-run` 세 사이클(홀더 3·2·4), 12개 답 전부 통과:

| 스텝 | 홀더 3 | 홀더 2 | 홀더 4 |
|---|---|---|---|
| 1 | 0.0090 | 0.0235 | 0.0335 mm |
| 7 | 0.0067 | 0.0040 | 0.0059 mm |
| 12 | 0.0269 | 0.0490 | 0.0617 mm |
| 18 | 0.0061 | 0.0370 | 0.0467 mm |

결정적인 줄은 스텝 7이다. 퍽을 어느 홀더에서 집어 왔느냐에 따라
0.0029/0.0339/0.1744 mm로 벌어지던 것이 0.0067/0.0040/0.0059 mm가 됐다 —
p-p 0.171 → 0.0027 mm, 63배. 이제 §14의 재접근 σ 0.022 mm보다도 작다.
즉 답이 더 이상 출처 홀더를 기억하지 않는다. ECC도 같이 올라갔다(홀더 4
스텝 7: 0.9953 → 0.9995) — 섞인 장면은 상관 자체도 갉아먹고 있었다.

스텝 12가 이제 가장 큰 값인 것(0.027–0.062 mm)은 결함이 아니다. 퍽이
실제로 놓인 자리가 사이클마다 그만큼 다르다는 뜻이고, 그건 세계 고정이라
재야 할 값이다. 12개 최대가 0.0617 mm로 `min_correction` 0.10 mm 아래다.

### 15.8 홀더마다 따로 떠야 하는가

랙 쪽 두 기준만 홀더별이고 샘플홀더 쪽 둘은 공용이다. 이제 교시 npz에
전체 프레임이 들어 있으므로, 이 갈래가 맞는지는 로봇 없이 확인된다 —
홀더 R의 기준을 홀더 F의 프레임에 대고 재보면 된다(3×3, 스텝 1과 18):

| | 같은 홀더 | 다른 홀더 |
|---|---|---|
| ECC | 1.0000 (자기 자신), 실측 답 0.9969–0.9997 | **0.4615–0.7658** |
| 되돌아온 이동량 | 0 | 0.20–0.48 mm |

**보정으로 메울 수 있는 차이가 아니다.** 홀더 간격 30 mm는 화면에서
~85 px이니 창을 그만큼 옮기면 될 것 같지만, 랙이 주기적이라 옮겨진 창은
*옆 홀더*에 정확히 내려앉는다. 그런데도 상관이 0.46–0.77까지밖에 안
올라간다 — 퍽과 컵이 홀더마다 실제로 다르게 생겼다는 뜻이고, 기하 보정이
지울 수 있는 종류의 차이가 아니다. 기준은 "그 홀더의, 그 퍽의" 사진이다.

주목할 점은 그때 되돌아오는 값이 85 px이 아니라 0.2–0.48 mm라는 것이다.
`max_correction` 3.0 mm 아래, `min_correction` 0.10 mm 위 — 그럴듯해
보이고 그대로 적용될 크기다. 이걸 막는 것은 `MIN_ECC` 0.90 하나이고,
0.7658(교차 최대)과 0.9723(§14.2가 20 사이클에 걸쳐 본 최악의 노후화)
사이에 있어 골짜기가 넓다. 다만 프로덕션에서 이 경우는 애초에 생기지
않는다 — 키에 `Robot:Holder`가 들어가므로 홀더 5의 런은 홀더 3의 기준을
고를 수 없고, 없으면 `Valid=0`으로 정지한다. 키가 1차 방어, ECC가 2차다.

반대로 스텝 7·12를 홀더별로 쪼갤 이유는 없다. 자세가 같고, §15.7의
0.0067/0.0040/0.0059 mm가 출처 홀더에 무관함을 보였다. 쪼개면 교시 비용이
3배가 되고, 같은 값을 세 번 재면서 그 무관함을 오히려 가린다.

홀더당 한 사이클이라는 비용은 그래서 남는다. 이걸 없애는 길은 저장 프레임
대신 모델 기준으로 가는 것이고, 그건 §15.11의 노후화 항목과 같은 문제다.

### 15.9 SIFT과 ROI 축소 — 강건함과 신원은 맞바꿔진다

두 대안을 교시 프레임으로 쟀다(로봇 없이). 스텝 1과 18이
`sequence.rs:313`/`:381`에서 같은 `w.standby`를 쓰므로 "같은 자세에서
슬롯 하나만 바뀐" 짝이 실재하고, 그게 시금석이다.

**SIFT** (게이트 마스크 안에서 검출, ratio 0.75, 중앙값 ±2 px inlier):

| 짝 | ECC | SIFT good/inlier, 이동, MAD |
|---|---|---|
| 같은 자세, 홀더 3 슬롯 비워짐 | **0.8681 → 거절** | 39/38, (+0.13,−0.13) px, 0.25 |
| h3 기준 vs h2 프레임 | 0.6808 → 거절 | 22/19, (−0.55,+0.74) px, 0.40 |
| h3 기준 vs h4 프레임 | 0.4809 → 거절 | 26/22, (−1.15,−0.48) px, 0.38 |

SIFT이 이기는 곳은 장면 변화다 — ECC가 `MIN_ECC` 0.90에 걸려 거절할 자리를
inlier 38개로 통과한다. 지는 곳은 신원이다: 틀린 홀더에 대고도 inlier
19–22개로 0.2–0.4 mm를 자신 있게 답하는데, 정상(38)과 자릿수가 같아 임계로
가를 수 없다. ECC는 0.48–0.68로 무너져 거절한다. 정밀도는 결정 요인이
아니다(ECC 0.0017 mm, SIFT ≈0.014 mm = MAD 0.25 px/√38, 팔 0.022 mm —
둘 다 팔 아래). `matchShapes`/Hu 모멘트는 병진 불변이라 이동량 자체를
주지 못한다; 신원 확인용이고 그 역할은 이미 ECC 상관이 한다.

**ROI 축소.** 표적 슬롯의 위치는 채운 프레임과 빈 프레임의 차이로 정확히
나온다 — 세 홀더 모두 y 313–361, x 273–342로 **같은 자리**다(standby가
홀더를 따라가므로 표적은 항상 화면 같은 곳에 온다). 그런데 그 영역은 공통
게이트의 7–9%뿐이다(1060/11983, 1318/17685, 1524/20542 px). 지금 ECC가
보고 있는 증거는 표적이 아니라 컬럼이라는 뜻이다.

| ROI | 게이트 | h3 vs h2 | h3 vs h4 | h2 vs h4 |
|---|---|---|---|---|
| 표적만 | 2906 px | 0.917 | 0.932 | 0.915 |
| +24 px | 4761 px | 0.941 | 0.945 | 0.957 |
| +40 px | 6476 px | 0.945 | 0.824 | 0.833 |
| +80 px | 11199 px | 0.768 | 0.617 | 0.488 |
| 현행 전체 컬럼 | 17759 px | 0.681 | 0.481 | — |

축소는 정확히 반대 방향이다. 표적만 남기면 교차 상관이 0.92–0.96으로
올라가 `MIN_ECC` 0.90을 넘는다 — 틀린 홀더의 기준을 받아들이고 ~1.0 px
(0.35 mm)를 답한다. 홀더들이 명목상 동일하므로 슬롯 하나만으로는 서로
구별되지 않는다. **이웃은 잡음이 아니라 신원의 증거다.**

두 실험이 같은 것을 말한다: 장면 변화를 무시하게 만드는 모든 것이 틀린
홀더도 무시하게 만든다. 현행 설계는 의도적으로 신원 쪽에 서 있고, 0.868
거절은 그 대가지 결함이 아니다.

남는 길은 2단이다 — 넓은 ROI로 신원을 확인하고 좁은 ROI로 이동량을 재는
것. 골짜기가 실재한다(틀린 홀더 ≤0.681, 슬롯 하나 바뀜 0.868): 임계
0.78이면 랙 적재 변화는 통과시키고 틀린 홀더는 막는다. 좁은 ROI의 잡음
바닥은 면적이 1/6이라 √6배인 0.004 mm로 팔보다 한참 아래다. 다만 0.868은
n=1이고 현행 단일 임계의 여유(0.681↔0.9953)보다 얇다. 미결.

### 15.10 2단 구현 — 넓은 창은 신원, 좁은 창은 이동량

**좁은 창을 손으로 잡지 않는다**(§15.3의 원칙). 한 사이클은 같은 자세를 두
번 지나가는데 퍽이 그리퍼의 반대쪽에 있다 — 랙은 스텝 1과 18이 같은
`w.standby`(`sequence.rs:313`·`:381`), 샘플홀더는 7과 12가 같은
`w.sh_standby`(`:326`·`:342`). 그래서 표적은 기술할 필요가 없다. **퍽을
가져갈 때 바뀌는 것이 표적이다.** 교시 런이 이미 두 프레임을 다 뜨므로
`pair_targets`는 사이클이 끝난 뒤 파일만 보고 계산한다 — 카메라도 팔도
필요 없고, 다시 돌려도 같은 값이다.

두 프레임 **모두** 게이트 안인 픽셀만 센다. 물린 퍽은 한쪽에서만 게이트
밖이고 다른 쪽에는 그 자리에 세계 고정 기하가 서 있어서, 교집합을 쓰지
않으면 프레임에서 가장 크게 "바뀐" 것이 표적이 아니라 **가림**으로 나온다
(처음 계산에서 실제로 그렇게 나왔다: y 423–480, 프레임 바닥).

도출된 표적은 세 홀더가 화면 같은 자리다 — standby가 홀더를 따라가므로
당연하다:

| 짝 | 표적 창 | 바뀐 픽셀 | 게이트 |
|---|---|---|---|
| `k1_s1_h2` + `k3_s18_h2` | (305,364,265,348) | 1060 px | 3561 px |
| `k1_s1_h3` + `k3_s18_h3` | (305,369,269,350) | 1249 px | 3870 px |
| `k1_s1_h4` + `k3_s18_h4` | (306,369,265,349) | 1524 px | 3897 px |
| `k3_s7` + `k1_s12` | (269,300,295,342) | 267 px | 888 px |

임계는 둘이고 서로 다른 질문에 답한다. `MIN_IDENTITY_ECC` 0.78은 §15.9의
골짜기(틀린 홀더 ≤0.681, 슬롯 하나 바뀜 0.868) 가운데이고,
`MIN_TARGET_ECC` 0.90은 표적 자체가 교시된 것인지를 본다.

저장 프레임으로 `observe`의 실제 경로를 6가지로 돌린 결과:

```
기준 자신                    |d|=0.0000 mm   identity 1.0000 / target 1.0000
틀린 홀더 h3<-h2             REFUSED   identity 0.6808 < 0.78
틀린 홀더 h3<-h4             REFUSED   identity 0.4809 < 0.78
틀린 홀더 h2<-h4             REFUSED   identity 0.4885 < 0.78
같은 자세, 표적이 비워짐        REFUSED   identity 0.8681 통과, target 0.2952 < 0.90
스테이지, 컵이 비워짐          REFUSED   identity 통과, target 미수렴
```

두 실패가 이제 **구분된다** — "여기가 그 홀더가 아니다"와 "홀더는 맞는데
표적이 그때 그것이 아니다"는 운영상 다른 사건이고, 로그가 그렇게 말한다.

실기 `check-run` 세 사이클, 12개 답 전부 통과:

| 스텝 | 홀더 3 | 홀더 2 | 홀더 4 |
|---|---|---|---|
| 1 | 0.0300 | 0.0191 | 0.0086 mm |
| 7 | 0.0076 | 0.0115 | 0.0042 mm |
| 12 | 0.0288 | 0.0536 | 0.0568 mm |
| 18 | 0.0135 | 0.0662 | 0.0208 mm |

identity 0.9981–0.9997, target 0.9917–0.9997. 최대 0.0662 mm로
`min_correction` 0.10 mm 아래이고, 단일 창 시절의 최대 0.0617 mm와 같은
크기다 — 창이 좁아져도(884–3897 px) 답이 나빠지지 않았다. 예상과 맞는다:
면적 비로 잡음 바닥은 0.004–0.008 mm이고 팔이 0.022 mm이므로, 지배하는
것은 여전히 팔이다.

**아직 못 잰 것 하나.** "이웃 슬롯이 바뀌어도 통과한다"는 것 자체는 랙을
물리적으로 바꿔야 재는데 그러지 않았다. 다만 이웃 픽셀은 측정 창 밖이라
구조적으로 답에 들어올 수 없고, 0.868은 슬롯 하나가 바뀌는 비용의
실측치다 — 어느 슬롯이든 바뀌는 픽셀 수는 1060–1524 px로 같은 크기다.

### 15.11 슬롯 점유 판정 — 충돌은 오차가 아니다 (2026-08-15)

홀더 1로 `teach-run`을 돌렸더니 짝짓기가 "두 프레임 사이에 바뀐 것이
없다"로 실패했다. 확인해 보니 홀더 1은 **빈 슬롯**이었다. 사이클은
정상 종료했다 — 그리퍼는 허공을 쥐었고, 아무것도 나르지 않았고,
샘플홀더에 아무것도 놓지 않았다. 스텝 7과 12의 프레임을 샘플홀더
표적창 안에서 비교하면 40 DN 넘게 바뀐 픽셀이 **0개**다(실제로 놓았다면
267 px). 시퀀스는 이걸 전혀 몰랐다.

빈 슬롯을 집는 것은 헛수고로 끝나지만 반대는 아니다. **이미 찬 슬롯에
놓으면** 손에 든 퍽을 앉아 있는 퍽에 박는다. 그래서 점유 판정은 정밀도
문제가 아니라 안전 문제다.

**임계값이 아니라 두 가설.** 재료는 이미 있었다. 자세마다 기준이 둘씩
있고(§15.10의 표적창을 만든 그 짝), 그 둘은 *같은 자세에서 같은 슬롯이
반대 상태인* 프레임이다. 그러니 점유는 "상관이 0.9를 넘느냐"가 아니라
"둘 중 어느 쪽을 더 닮았느냐"다. `seat_state(kind)`가 어느 쪽이어야
하는지 말해 준다 — 찬 자리에서 집고 빈 자리에 놓으므로 kind가 이미
답이다. 유지할 표가 늘지 않는다.

여백은 크다. 교시된 프레임 8개를 각자의 정지점에서 재생하면 자기
가설에 1.0000, 반대 가설에 0.2014–0.2952(샘플홀더 쪽은 아예 수렴
실패). 실기 사이클(홀더 3)에서도 0.9973–0.9996 대 0.2033/0.2768이다.
0.90 바닥선과 달리 이 여백은 기준이 낡아도(§14.2의 0.9723) 뒤집히지
않는다.

**수렴 실패는 별종의 실패가 아니라 반대 증거다.** 처음 구현은 기대
가설의 ECC가 수렴하지 않으면 거기서 "상관이 수렴하지 않았다"로
돌아섰다. 홀더 1의 빈 샘플홀더가 정확히 그 경우였다 — 찬 기준에 수렴
실패, 빈 기준에 0.9986. 즉 사고를 가장 정확히 설명하는 프레임이 가장
쓸모없는 메시지를 받는다. 두 가설을 **먼저 다 채점하고** 그 다음에
판단하도록 고쳤고, 그러자 "여기엔 집을 것이 없다"가 나온다.

**신원 검사가 우선순위를 지키되 증거는 넘긴다.** 순서는 신원 → 점유다.
엉뚱한 홀더에서는 표적창이 다른 슬롯을 보고 있으니 그 슬롯에 대한
자신만만한 판정은 없느니만 못하다. 그런데 홀더 2는 적재 상태가 바뀐
것만으로 신원이 0.6713까지 떨어진다 — 신원 단계가 점유 단계보다 먼저
거절해 버린다. 그때 "기준과 맞지 않는다"만 받은 작업자는 기준을 다시
교시할 수 있고, 그러면 **잘못 적재된 랙이 기준으로 굳는다**. 그래서
신원 실패 메시지에도 좌석 증거를 붙인다.

검증은 `tools/vision/occupancy_check.py`가 한다. 라벨이 붙은 프레임
22개를 **`Node.observe` 자체에** 재생한다(비교 로직을 옮겨 적지 않는다 —
베낀 검사는 어느 한쪽을 고치는 순간 검사가 아니게 된다). 22/22 정답:
정상 8개는 답하고, 충돌 경우 4개와 빈 집기 경우 4개는 거절하고, 홀더 1
사이클의 6개는 전부 거절한다.

**아직 아무것도 막지 못한다.** `config/sequencer.yaml`의
`vision.enabled: false`다. 그리고 `observe_only: true`는 `!r.valid`를
로그만 남기고 삼킨다(`sequence.rs:948`). 즉 이 판정이 실제로 충돌을
막으려면 `enabled: true` + `observe_only: false`여야 하고, 그건
보정까지 같이 켜는 스위치다. **충돌 가드와 서브밀리미터 보정이 스위치
하나에 묶여 있다** — 가드만 원하는 운전은 지금 표현할 수 없다. 분리할지는
결정 사항으로 남긴다.

### 15.12 남은 것

- **나머지 홀더.** 랙 쪽 두 기준(`k1_s1_h*`, `k3_s18_h*`)은 홀더마다 따로
  필요하다. 3·2·4는 있고, 1과 5–10은 없다. 홀더를 바꿔 `teach-run`을 다시
  돌리면 된다. 홀더 1은 **퍽을 꽂은 뒤에** 해야 한다 — 빈 슬롯에서 뜬
  기준은 스텝 1이 기대하는 상태가 아니고, 그래서 §15.11의 두 파일은
  지웠다.
- **점유 가드가 꺼져 있다.** §15.11의 판정은 `vision.enabled: false`인
  동안 아무것도 막지 않는다. 켜는 결정과, 가드를 보정과 분리할지는
  아직 안 정했다.
- ~~PlaceAlign ROI의 툴 고정 오염~~ — §15.7에서 닫음.
- **기준이 낡는 문제.** §14.2가 20 사이클에 걸쳐 ECC 상관이 0.9981 →
  0.9723으로 단조 감소하는 것을 봤다. 저장 프레임 기준의 한계이고, 재교시
  주기를 정하든 모델 기준으로 옮기든 답이 필요하다. 아직 답이 없다.
- **Phase 2(관찰 모드) 미실행.** `observe_only: true`로 8지점(현재 4지점)
  분포를 쌓는 단계가 그대로 남아 있다. 이 노드는 그걸 돌릴 수 있게 된
  것이지, 그걸 대신한 것이 아니다.
- Grip Offset과 Seating은 여전히 미측정.

## 16. 힘 — 이미지 정렬이 대신하던 그 판정 (2026-08-15 실측)

보정이 맞았는지의 최종 기준은 **퍽이 걸리지 않고 들어가고 나오는가**다.
옆에 걸려 흔들리면 시료가 데미지를 입는다. 이미지 일치도는 그것의
대리지표이고, 좋은 대리지표이지만 대리지표다 — 테두리를 보고 판단하는데,
퍽이 따라가야 하는 것은 보어의 축이다. 그 둘이 어긋난 컵은 ECC가 볼 수
없다.

### 16.1 팔이 무엇을 느끼는가 — 무게는 못 느끼고 접촉은 크게 느낀다

UR3e의 `actual_TCP_force`는 손목 센서가 아니라 관절 전류 추정이다. 그래서
"퍽을 들었는지 무게로 아는가"와 "벽에 닿았는지 아는가"는 서로 다른 질문이고,
답도 달랐다.

모니터 IOC의 `ActualTCPForce`는 0.5 Hz라 삽입 한 번을 못 담는다. RTDE
출력(30004)은 클라이언트별 레시피로 다중화되므로 데몬을 내리지 않고 두 번째
읽기 전용 클라이언트를 붙였다 — `src/bin/force_log.rs`,
`["timestamp","actual_TCP_force","actual_TCP_pose","actual_q"]`, 125 Hz,
입력 레시피 없음. 15 사이클 231,961 표본 / 1855.7 s를 받았다
(`vision_survey/force_125hz.csv`).

**정지 상태 (`force_lift.py`).** 정지 구간 13회가 모두 한 자세로 묶였다.
Fz 평균 4.348 N, **스톱 내 표본 표준편차 0.0730 N**, 스톱 간 평균의
표준편차 0.042 N. 절대값은 팔 자신의 모델 오차와 페이로드를 달고 있다
(같은 자세에서 Fy = -33.854 N). 쓸 수 있는 것은 절대값이 아니라 **차이**다.

**무게로는 못 가른다.** 로드/언로드 두 방문을 가르려 했으나 13회의 최대
간격이 0.029 N, 두 무리 분리 0.078 N 대 산포 0.0730 N이다. 퍽 무게는 이
자세에서 이 방법으로 **분해되지 않는다**. 무게 기반 판정은 여기서 접었다.

**접촉은 두 자릿수로 가른다 (`force_insert.py`).** 수직 구간 17개
(각 5 mm 안팎, x/y 고정):

| 성격 | 구간 수 | 측면력 변화 |
|---|---|---|
| 자유 공기 | 7 | 0.56 – 1.07 N |
| 접촉/마찰 | 10 | 8.46 – 22.94 N |

정지 잡음 0.073 N 대비 자유 공기가 8–15배(관성이지 접촉이 아니다),
접촉은 다시 그것의 8–20배다. **신호는 크고, 문제는 잡음이 아니라 언제
읽느냐다.**

스테이션별 평균 측면 최대치 — 이것이 홀더별 오프셋이 결국 겨눠야 할 수치다:

| 스테이션 | x (mm) | y (mm) | 구간 | 하강 | 상승 |
|---|---|---|---|---|---|
| 0 (랙) | -75.6 | -334.9 | 14 | 5.612 N | 7.901 N |
| 1 (샘플홀더) | 342.4 | -151.9 | 8 | 9.874 N | 5.305 N |

### 16.2 그립력과 틈새 — 무엇이 상한이고 무엇이 하한인가

**그립력은 상한이 아니다.** `gripper.rs:99`가
`driver.set_position(target, 1.0)` — Hand-E를 전 스케일로 닫고 시료에
물려 정지시킨다. 1–2 N으로 미는 프로브가 미끄러뜨릴 수 있는 값이 아니다.
(실제 파지력 자체는 여전히 미측정 — rCU 레지스터가 노출돼 있지 않고
54321은 단일 소유자라 데몬을 내리지 않고는 못 읽는다.)

**하한은 시료다.** 퍽 안에 무엇이 들었는지 코드가 모르므로, 천장은 설정값이고
기본값은 하드웨어가 견디는 곳이 아니라 **접촉이 명백해지는 곳**에 뒀다
(0.5 N 접촉 / 5.0 N 중단).

**틈새.** 퍽 섕크 Ø19.00 mm, 머리 Ø25.20 mm. 랙 보어는 Ø20.00 mm로 보이며
(축 하나는 Ø20.50이 나와 아직 확정 아님) 그렇다면 반경 여유 **0.50 mm**다.
§15.6이 측정한 홀더별 y 잔차 0.21–0.30 mm는 그 여유의 **42–60%**를 먹는다.
접촉이 관측되는 이유가 여기 있고, y가 하필 `sequence.rs`의 홀더별 항이
**없는** 유일한 축이다(x·z는 표가 있고 y는 `(holder-1) * holder_offset`
하나뿐인데, 실측 피치 오차가 -0.2123 vs -0.0883 mm로 균일하지 않아
`holder_offset` 하나로는 흡수되지 않는다).

### 16.3 힘으로 멈추는 이동 (`motion/probe.rs`, `CalibMode=5`)

**왜 궤적을 취소하지 않고 스텝을 밟는가.** 느린 이동을 걸고 힘이 뜨면
취소하는 쪽이 자연스러워 보이지만 §16.1이 두 가지를 막는다. 첫째 잡음 —
움직이는 중의 0.56–1.07 N을 넘어야 하는 임계는 1 N 위에 서고, 그건 실제
마찰이 시작되는 값이다. 스텝 사이 정지 상태에서 읽으면 0.073 N만 넘으면
되고 0.5 N은 거기서 7σ다. 둘째 오버슈트 — 취소된 이동도 감속하고 그
감속 중 쌓이는 힘은 시료에 걸린다. 스텝에는 털어낼 운동량이 없어
최악이 `step_mm` 한 걸음이다. 비용은 벽시계 시간이고, 커미셔닝
작업이라 그건 싼 축이다.

**왜 답이 임계값에 의존하지 않는가.** 임계는 *멈추는* 시점을 정할 뿐이고,
답이 "멈춘 위치"라면 임계가 답을 옮긴다. 답은 그게 아니다 — 가로 벽도
세로 바닥도 전부 `Contact::wall_mm`이 낸다. 접촉 이후 표본을 직선 적합해
**접촉 전 힘이 앉아 있던 수준으로** 외삽하고, 그 절편이 벽이다. 기울기가
*시작된* 자리는 금속의 성질이고, 어떤 수준이 *넘어간* 자리는 임계와
스텝 크기의 성질이다. 마지막 한 점이 아니라 모든 스텝을 남기는 이유가
이것이고, 접촉에서 곧장 돌아오지 않고 몇 스텝 더 밟는(`overtravel_steps`)
이유도 이것이다.

처음부터 한 규칙이었던 건 아니다. 바닥만 적합하고 가로 두 벽은 트립
위치를 썼다 — "늦게 트립하는 임계는 양쪽을 같은 만큼 바깥으로 밀고
중점은 그대로 둔다"는 논거였다. 양쪽이 같은 방식으로 걸릴 때만 성립하고,
실제 자리는 그렇지 않다: 2026-08-18에 `base x+`는 0.25 N 끌림 위로
0.7 mm에 걸쳐 램프였고 `base x-`는 잡음에서 한 스텝에 트립했다(§16.8).
한 파일 안에 "닿은 자리"의 정의가 둘이었던 것이 원인이라 이제 하나다.
0으로가 아니라 **베이스라인으로** 외삽하는 것도 같은 런이 시켰다 — 끌고
가는 프로브는 만나기 전부터 일정한 힘을 읽고, 그걸 0으로 외삽하면 벽이
0.06 mm 앞당겨진다. 베이스라인은 트립 이전 표본의 중앙값, 잡음 폭은 그
중앙값 절대편차다(평균이 아닌 이유는 접촉 표본 하나가 평균을 끌기
때문).

**이동량은 명령이 아니라 FK로 잰다.** 접촉 중에는 서보가 자리를 내주므로
명령한 0.05 mm가 다 들어가지 않는다. 힘이 붙는 대상은 실제로 내준 자리다.
덤으로, 명령한 스텝이 **아예 실행되지 않는** 경로가 있다(§16.5). 밀리지도
않았는데 힘도 없으면 에러 — 지나간 적 없는 거리를 틈새로 보고하는 것보다
멈추는 게 낫다.

**복귀는 `move_direct`, `move_cartesian`이 아니다.** 후자는 직선이 모자라면
`move_planned`(RRT)로 대체 실행하는데, RRT-Connect가 1 mm 떨어진 두 자세를
잇느라 TCP를 0.71 m 휘두른 것이 핸드아이 캡처에서 실측됐다. 퍽이 앉은
채로 그건 먼 길이 아니라 시료를 옆으로 끌어내는 동작이다.

**운영 절차** — 다른 캘리브레이션 모드와 같은 2회 트리거:

```bash
caput Robot:CalibMode 5
caput Robot:Trigger 1     # 1회차: jog hold. 퍽을 쥐고 자리에 내린다.
                          #         JogX/Y/Z + JogStep, Gripper PV 모두 동작.
caput Robot:Trigger 1     # 2회차: 현재 자세에서 x·y 브래킷, z 바닥 탐침.
```

결과는 **로그로만** 나온다. `CurrentStep`은 건드리지 않고, 팔은 프로브를
시작한 자세에 남는다 — 이 모드는 손에 시료를 든 채 시퀀스 중간에 들어오는
것이고, 보어에서 퍽을 어떻게 빼는지 정하는 것도 런이 끝났다고 선언하는
것도 여기 할 일이 아니다. 그 자세가 "자리 안"인지는 데몬이 아는 사실이
아니다 — jog hold에서 조작자가 그렇게 주장한 것이고, 아무 벽도 못 만난
런이 바로 그 주장이 틀렸던 경우다. 그래서 리포트는 "프로브를 시작한
자세로 돌아왔다"까지만 말한다(복귀는 실패하면 에러라 이건 아는 사실이다).

### 16.4 스텝이 사라진다 — TOTG가 웨이포인트를 버리는 경계 (2026-08-15 실측)

첫 실기 프로브가 `commanded 0.050 mm and moved -0.011 mm`로 정지 가드에
걸렸다. 팔은 정상이었고 힘도 없었다. **명령이 실행되지 않았다.**

원인은 시간 파라미터화다. `apply_totg_time_parameterization(...,
min_angle_change)`은 어느 조인트도 `min_angle_change`보다 더 움직이지
않은 웨이포인트를 버린다 — 플래너 출력의 중복점을 걸러내려는 상류의
장치지 팔의 물리적 한계가 아니다. 그런데 점이 하나만 남은 궤적은
`execute.rs`의 `if n < 2 { return Ok(()) }`에 걸려 **성공으로 처리된다.**
이동은 "완료됨"으로 보고되고 전송된 적이 없다.

실기 스윕(`tools/vision/step_floor.py`, 각 크기마다 5스텝 왕복 삼각파의
진폭÷5):

| 명령 | 도달 |
|---|---|
| 0.05 mm | 0.000 mm |
| 0.10 mm | 0.000 mm |
| 0.20 mm | 0.202 mm (101%) |
| 0.30 mm | 0.302 mm |
| 0.50 mm | 0.504 mm |
| 1.00 mm | 1.006 mm |

**큰 스텝은 해결책이 아니다.** 경계가 자세에 의존하기 때문이다. 0.20 mm는
`holder1_standby`에서 1.029e-3 rad(기본 임계 1e-3을 겨우 넘김)이지만
`sample_holder_on_position`에서는 7.53e-4 rad로 **버려진다**. 즉 같은 명령이
한 자세에서는 실행되고 다른 자세에서는 조용히 사라진다. 게다가 반경 틈새가
0.50 mm 수준인데 0.30 mm 스텝은 분해능이 없다.

구조적 수정은 임계를 호출자가 정하게 하는 것이다. `timed_execute`가
`min_angle_change`를 인자로 받고, 시퀀스의 모든 이동은 기존 `MIN_ANGLE_CHANGE
= 1e-3`을 그대로 쓰며, 프로브만 `jog_fine` → `FINE_MIN_ANGLE_CHANGE = 1e-8`을
쓴다. 1e-8은 여전히 float 잡음보다 한참 위라 진짜 중복점은 전과 같이
버려지고, 프로브 스텝이 만드는 가장 작은 조인트 변화보다는 네 자릿수
아래다. 단위테스트
`a_probe_step_is_smaller_than_totg_keeps_by_default`가 교시 자세 두 곳에서
양쪽 경계를 모두 고정한다.

수정 후 자유 공기에서 스텝 증분 ~0.051 mm, 산포 0.007 mm. `STEP_TAKEN_FRACTION`
가드는 남겼다 — 조용한 no-op은 이 프리미티브가 감당할 수 없는 실패고, 이번에
찾은 메커니즘이 유일하다는 보장이 없다.

**같은 이유로 한 패키지 읽기를 버렸다.** 정지 상태에서 자세는 샘플당
0.004–0.007 mm 흔들리고 한 정지 구간 전체로 0.046 mm를 훑는다 — 0.05 mm
스텝의 대부분이다. `Session::mean_q_and_wrench(25)`가 **같은** 25개
패키지에서 자세와 렌치를 함께 평균한다. 125 Hz에서 0.2초고, 자세 산포는
마이크론 아래로 떨어지며, "얼마나 갔나"와 "무엇이 밀었나"가 서로 다른
순간을 답하지 않는다.

### 16.5 아직 아닌 것

- **자유 구간을 만난 적이 없다.** 자유 공기 주행은 정지 가드와 잡음
  바닥을 실측했고(2026-08-15, 가로 4회 × 30스텝 + 세로 40스텝, 173초,
  힘 변화 0.234 N 이하), 착좌 상태 주행은 접촉을 실측했다(§16.6). 아직
  없는 것은 그 사이 — 벽에 닿기 전에 자유롭게 지나가는 구간이다. 가로
  세 방향 모두 **첫 스텝**에서 걸린다.
- **표에 쓰지 않는다.** "보어 중심이 base y로 +0.23 mm"를 웨이포인트
  표의 변경으로 옮기는 것은 여러 홀더의 수치를 놓고 내리는 랙에 대한
  결정이다. 방금 접촉까지 밀고 들어간 모드가 혼자 내릴 결정이 아니다.
- **보어 치수 미확정.** Ø20.00과 Ø20.50 후보가 갈린다. 보어 깊이도 모른다 —
  수직 구간이 5.0 mm인데 섕크는 12 mm라, `above` 자세에서 이미 물려 있는지
  아닌지가 정해지지 않았다.
- **관성과 접촉을 파형으로 분리하지 않았다.** 자유 공기 0.56–1.07 N이
  관성이라는 것은 구간 성격으로 갈랐지, 파형으로 증명하지 않았다.

### 16.6 착좌 상태 프로브 — 파지를 풀어도 같은 벽 (2026-08-15 실측)

홀더 4에 퍽을 넣고 `PauseStep=4`로 스텝 4(close_gripper)에서 멈춘 뒤
`Wait=2`로 시퀀스를 세우면, 팔은 `holder_on_position`에서 퍽을 문 채
그대로 선다. 여기서 `CalibMode=5` + 트리거 2회가 프로브다. 같은 홀더
같은 자세에서 두 번 돌렸다 — 한 번은 문 그대로, 한 번은 손가락만
0.4 mm 벌리고.

| 방향 | 문 그대로 (10:35) | 0.4 mm 벌림 (10:52) |
|---|---|---|
| base x+ | +0.038 mm, along 1.208 N, lateral 1.641 N | +0.024 mm, along 0.730 N, lateral 1.559 N |
| base x− | +0.051 mm, along 1.549 N, lateral 0.979 N | +0.061 mm, along 1.593 N, lateral 0.623 N |
| base y+ | +0.052 mm, along 6.293 N → **abort** | +0.048 mm, along 6.008 N → **abort** |
| base z− | 실행 안 됨 (y+ abort가 앞섬) | 실행 안 됨 (y+ abort가 앞섬) |

**0.4 mm는 유격이 아니었다.** 처음에는 문 쪽과 벌린 쪽이 산포 안에서
같아서 "파지는 저항의 경로가 아니다"라고 적었다. 틀렸다 — 0.4 mm는
편측 0.2 mm뿐이고 공칭 반경 여유 0.50 mm보다 작다. 즉 손가락은 여전히
퍽에 닿아 있었고, 폐루프는 열린 적이 없다. 세 번째 런에서 유격을
1.275 mm(편측 0.64 mm)로 키우자 같은 방향이 **6.008 N → 0.652 N**,
9배 떨어졌다. **base y+의 6 N은 파지 폐루프였다.**

| 방향 | 1.275 mm 벌림 (08-18 09:36) |
|---|---|
| base x+ | +0.052 mm, along 0.970 N, lateral 0.709 N |
| base x− | +0.054 mm, along 0.256 N, lateral 1.037 N |
| base y+ | +0.051 mm, along 0.652 N, lateral 1.053 N |
| base y− | +0.052 mm, along 2.439 N, lateral 1.634 N |
| base z− | +0.078 mm, along −1.285 N, lateral 2.099 N |

abort가 사라져 네 방향이 처음으로 다 돌았고 base z−도 처음 실행됐다.
판정은 base x 중심 −0.001 mm / 틈새 0.053 mm per side, base y 중심
−0.000 mm / 0.051 mm per side.

**세로 여유는 착좌 상태에서 재본 적이 없다.** 두 런 모두 base y+가
abort하면서 depth 프로브 앞에서 끝났다. 같은 날 10:34 런이 base z−로
4.21 mm를 0.070 N에 주행했지만 그 런은 **보어 밖**이었다 — 같은 런에서
base x와 base y도 1.50 mm 안에 아무것도 없었다("nothing within 1.50 mm
either way"). 자유 공기 수치를 착좌 여유로 읽으면 안 된다.

**축 대응 (holder_on_position, 프로브 로그에서 직접).** `base x+`는
`TCP Jog dx`, `base y±`는 `dz`, `base z−`는 `dy=+0.100`으로 나간다. 즉
tool x = base x, **tool y = base −z(아래)**, tool z = base +y(수평,
그리퍼 접근축). 교시 파일도 같은 말을 한다 — `above_y_offset: -0.005`는
`Model::apply_cartesian_offset`의 TCP-local 오프셋이므로 tool y로 −5 mm,
곧 위로 5 mm다. 삽입 구간 5.0 mm가 이 축이고, 세로 = base −z = tool +y다.
따라서 6 N이 나온 base y+는 세로가 아니라 **가로**, 그것도 그리퍼가
바라보는 방향이다.

**그런데 그 대칭이 측정이 아니다.** 네 방향이 모두 *첫* 스텝에서,
+0.051 ~ +0.054 mm에서, 즉 **한 스텝의 절반**에서 걸렸다. 방향과
무관하게 한 스텝이면 걸리는 계는 어느 쪽으로 재도 "틈새 = 스텝/2"를
돌려준다. 중심이 −0.001, −0.000 mm로 나온 것은 보어가 가운데 있다는
뜻이 아니라 **양쪽이 같은 한 스텝에서 걸렸다**는 뜻이다. 편측 유격이
0.64 mm인데 0.05 mm에서 걸렸으므로 손가락–퍽 접촉일 수도 없다.

**트립 판정이 방향을 안 가린다.** `probe.rs:383`이
`felt = along.abs().max(lateral)`다. base x−는 along이 0.256 N으로
임계 아래인데 lateral 1.037 N으로 트립했다 — 미는 방향과 직교한 힘은
그 방향의 접촉이 아니다. 다만 자유 공기 런(prod13 10:34)은 같은 스텝을
30회 돌려 0.149 N을 넘지 않았으므로, 이 0.25–2.4 N을 스텝 전이로만
설명할 수도 없다. 무엇이 0.05 mm에서 밀어내는지는 아직 미상이다.

**앞선 두 런의 상한 해석은 유지된다.** 기록된 `+0.024`/`+0.061` mm는
벽의 위치가 아니라 **자유 구간의 상한**이다.

### 16.7 2.5 mm 벌리자 자유 구간이 나왔다 (2026-08-18 실측)

유격을 2.549 mm까지 키운 네 번째 런에서 처음으로 스텝 하나에서 끝나지
않았다. 같은 홀더 4, 같은 자세, 같은 임계다.

| 방향 | 결과 |
|---|---|
| base x+ | +1.102 mm에서 접촉 (0.078 → 0.509 N로 21스텝에 걸쳐 상승) |
| base x− | 1.50 mm까지 접촉 없음, along 0.06 N 이하 |
| base y+ | 1.50 mm까지 접촉 없음 |
| base y− | −1.039 mm에서 접촉 |
| base z− | **바닥 +0.910 mm** (힘–깊이 피팅), 트립 +1.044 mm |

**유격 계단이 곧 진단이다.** 0.4 mm → 1.275 mm → 2.549 mm로 키우는 동안
base y+가 6.008 N → 0.652 N → 접촉 없음으로 갔다. 앞의 두 런에서 첫
스텝을 막던 것은 손가락이었다. 편측 자유 구간이 1.5 mm 주행보다 커진
뒤에야 팔이 무엇을 만나는지 물어볼 수 있게 됐다.

**세로가 처음으로 답을 냈다.** 0.6 mm까지 0.05 N으로 평평하다가
−0.454 / −0.730 / −2.065 N으로 꺾인다. 상승 표본이 넷이라 피팅이 성립하고,
교시 `holder_on_position`이 바닥보다 **0.91 mm 위**라는 뜻이다. 퍽 머리가
Ø25.20으로 Ø20 보어에 못 들어가므로 그 바닥은 랙 상면이다.

**가로 두 방향은 아직 정체 미상.** +1.10 / −1.04 mm는 공칭 지름 여유
1.0 mm와 크기가 맞지만, 반대 두 방향이 1.50 mm까지 아무것도 못 만난
것과는 맞지 않는다(퍽이 한쪽 벽에 붙어 있었다면 그쪽은 즉시 걸려야
한다). 손가락이 홀더 포켓 벽에 닿는 것일 수도 있다. 손가락을 완전히
열거나 퍽 없이 같은 프로브를 돌리는 대조가 이것을 가른다.

(앞의 0.4 mm 쌍에 붙는 관찰이다: 거기서는 한 스텝의 실제 주행이
0.024–0.061 mm로 흩어졌다 — 명령은 셋 다 0.050 mm였고, 재려는 양과 같은
크기의 산포다. 그래서 두 판정 "중심 −0.007 mm, 틈새 0.044 mm/측" vs
"중심 −0.018 mm, 틈새 0.042 mm/측"이 11 µm 안에서 겹친 것은 반복성의
증거지 분해능의 증거가 아니었다. 이번 런은 스텝이 자유 구간보다 작으므로
그 제약을 받지 않는다.)

**파지 위치는 닫힘 대기가 보고하는 값이 아니다.** 스텝 4 로그는
`pos=0.0095`지만 손가락이 멈춘 곳은 `0.0037 m`다. `reach_tolerance`가
1.5 mm라 닫힘 대기는 손가락이 그 띠를 지나는 순간 빠져나온다. 프로브의
`loosen_by`/`regrip` 쌍은 정지(stall)로만 기다리며, 복원이 `0.0037`로
정확히 돌아온 것이 그 대기가 실제로 끝을 본다는 증거다.

다음에 갈릴 것: 손가락을 **완전히** 열고(퍽을 보어에 놓고) 같은 프로브를
돌리면 가로 접촉이 손가락–홀더인지 퍽–보어인지 갈린다. 이번에는 하지
않았다 — 퍽을 문 상태를 유지하라는 지시였다. 그리고 자유 구간을 재려면
가로 스텝이 그 구간보다 작아야 하는데, 그 전에 한 스텝의 주행 산포
(±0.03 mm)를 먼저 줄여야 한다.

### 16.8 가로 3 mm — 네 방향 모두 벽을 찾았다 (2026-08-18 실측)

`probe.lateral.travel_mm`을 1.5 → 3.0으로 올린 다섯 번째 런. 같은 홀더 4,
같은 자세, 같은 유격(2.549 mm), 같은 임계. 이번에는 네 방향이 다 걸렸고
브래킷 둘이 처음으로 닫혔다.

| 방향 | 접촉 | 접촉 직전까지 |
|---|---|---|
| base x+ | +1.116 mm | 0.3–1.0 mm 구간에서 along이 0.22–0.27 N로 **평평** |
| base x− | −2.037 mm | 1.99 mm까지 along ≤0.26 N |
| base y+ | +1.829 mm | 1.78 mm까지 along ≤0.28 N |
| base y− | −0.990 mm | 0.94 mm까지 along ≤0.17 N |
| base z− | 바닥 +0.947 mm | 트립 +1.088 mm |

브래킷은 base x 중심 **−0.461 mm** / 틈새 1.576 mm per side, base y 중심
**+0.420 mm** / 1.410 mm per side.

**반복성은 확인됐다.** 1.5 mm 런과 겹치는 세 값이 x+ 1.102 → 1.116,
y− 1.039 → 0.990, 바닥 0.910 → 0.947로 모두 0.05 mm 안에서 다시 나왔다.

**그러나 이 중심은 보어 중심이 아니다.** 편측 틈새 1.41–1.58 mm는 공칭
반경 여유 0.50 mm의 세 배다. 두 벽 사이의 총 주행은 base x 3.153 mm,
base y 2.819 mm인데 손가락 유격이 2.549 mm다 — 프로브가 주행한 구간의
대부분은 보어가 아니라 **패드 사이의 유격**이고, 유격을 넘는 초과분은
x 0.604 mm, y 0.270 mm뿐이다. 자유 구간을 만들려고 넣은 유격이 그대로
측정하려던 양의 불확실성이 됐다: 패드가 놓아준 뒤 퍽은 보어 안 어디에나
있을 수 있고, 브래킷의 중점은 그리퍼가 그 퍽에 대해 가운데 서는 곳이지
보어가 가운데인 곳이 아니다. **이것은 튜닝이 아니라 방법의 한계다** —
파지를 풀어야 자유 구간이 생기고, 파지를 풀면 퍽의 위치가 풀린다.

**base x+만 끌린 흔적이 있다.** 0.3 mm에서 1.0 mm까지 along이 0.22–0.27 N로
일정하다. 나머지 세 방향은 마지막 한 스텝에서 노이즈(≤0.26 N)에서 임계
위로 튄다. 일정한 저항은 무언가를 끌고 가는 힘의 모양이고, 한 스텝의
계단은 단단한 벽의 모양이다.

**트립 판정 결함은 이번 런에서는 물지 않았다.** 네 접촉 모두 along 단독으로
임계를 넘었다 (+0.747 / +0.744 / +0.594 / +1.233 N). `probe.rs:383`의
`felt = along.abs().max(lateral)`은 고치지 않은 채 남아 있다.

**다음 대조.** 퍽 없이(빈 손가락) 같은 자세·같은 유격으로 같은 프로브를
돌리면 갈린다 — 같은 자리에 벽이 나오면 그 벽은 손가락과 랙 사이의
것이고 보어와 무관하다. 3 mm 안에 아무것도 없으면 벽에 퍽이 관여한다.

### 16.9 벽의 정의를 하나로, 그리고 그게 드러낸 것 (2026-08-18 실측)

§16.8까지의 숫자는 전부 **트립 위치**다. 임계를 넘은 스텝이 선 자리이고,
그 안에는 임계값과 최대 한 스텝의 오버슈트가 들어 있다. 세로 바닥만
처음부터 적합(`touch_at`)이었다 — 한 파일 안에 "닿은 자리"의 정의가 둘.
가로가 트립 위치여도 됐던 논거는 "늦게 트립하는 임계는 양쪽을 같은 만큼
밀어 중점에서 상쇄된다"였는데, §16.8이 그 전제를 깼다: `base x+`는
0.25 N 끌림 위로 0.7 mm 램프였고 `base x-`는 한 스텝에 튀었다. 상쇄될
수가 없다.

그래서 `Contact::wall_mm` 하나로 합쳤다. 접촉 이후 표본을 직선 적합하고
**접촉 전 힘이 앉아 있던 수준(베이스라인)** 으로 외삽한다. 0이 아니라
베이스라인인 이유가 그 끌림이다. 브래킷은 양쪽을 **같은 추정기**로만
낸다 — 한쪽만 적합하고 다른 쪽은 트립이면 그 차이가 통째로 중점 편향이
되므로, 한쪽이 적합 불가면 양쪽 다 트립으로 내려간다.

두 번의 실기 런이 설계 실수 두 개를 잡아냈다.

**하나 — 오버트래블이 abort를 일으켰다.** 접촉 후 램프 표본을 얻으려고
3스텝을 더 밟게 했더니 `base y+`에서 2.48 N → 5.24 N으로 올라 5.00 N
abort에 걸렸다(11:09). **이미 찾은 것을 재려다 런을 죽인 것**이다.
스텝 수만이 아니라 힘으로도 멈춰야 한다 — abort의 절반에 닿으면 표본을
더 요구하지 않는다. 그러면 abort는 원래 뜻으로 돌아간다: 한 스텝이
직전 스텝보다 훨씬 단단한 것을 만났다.

**둘 — 잡음 컷을 통계로만 잡으면 세로가 망가진다.** 램프 시작점을
"베이스라인 + 3×중앙값절대편차"로 잡았더니, 세로의 산포가 0.1 N 근처라
바닥 0.5 mm 위에 있는 **0.4–0.5 N 어깨**가 램프에 들어왔다. 기울기가
16 N/mm에서 4.5 N/mm로 깎이고 바닥이 0.933 → 0.718 mm로 밀렸다(11:23).
어깨는 바닥이 아니다. 컷은 그 런의 산포와 **축 임계의 절반** 중 큰
쪽이다. 그러면 세로는 임계 아래에 램프 표본이 없어지므로 세로에도
오버트래블이 필요해진다(2스텝, 힘 상한 4 N).

고친 뒤 같은 홀더·같은 자세·같은 유격(2.549 mm):

| | prod21 (트립) | prod25 (x만 적합) | prod27 (전부 적합) |
|---|---|---|---|
| base x 중심 | −0.461 | −0.473 | **−0.452** |
| base x 틈새/측 | 1.576 | 1.528 | 1.528 |
| base y 중심 | +0.420 | +0.416 (트립) | **+0.486** |
| base y 틈새/측 | 1.410 | 1.401 (트립) | 1.466 |
| base z 바닥 | 0.947 | 0.718 (컷 결함) | **0.933** |

세로는 접촉(−2.431 N)에서 한 스텝 더 가 −4.022 N에서 힘 상한에 걸려
멈췄고, 그 두 점이 바닥을 냈다. 가로도 각 방향 한 스텝씩만 더 갔다.

**적합이 트립보다 더 말해준다.** prod25의 `base y+`는 접촉 후 힘이
0.548 → 0.532 → 0.493 → 0.518 N로 **평평**했다. 벽이면 더 밀수록 더
단단해야 하는데 그렇지 않으니 적합은 거절했고, 브래킷은 트립으로
내려갔다. 일정한 힘은 **끌고 가는 중**이라는 뜻이다 — 패드가 퍽을 만나
밀고 있는 것이지 퍽이 보어에 닿은 것이 아니다. 트립 위치는 이 둘을
구분하지 못하고 둘 다 "벽"이라 부른다. §16.8이 남긴 질문(가로 접촉의
정체)에 대해, 적합의 거절 자체가 증거의 한 조각이다.

### 16.10 티칭된 착좌 자세는 퍽을 5 N으로 누르고 있다 (2026-08-18 실측)

§16.6–16.9의 브래킷은 전부 **파지를 푼** 상태였고, 남은 질문은 꽉 문
채로는 어떤가였다. 스텝 4에서 멈춰(`PauseStep=4` → `Wait=2`) 퍽을 문
채로 `CalibMode=5`를 돌리면 티칭된 `holder_on_position`에서:

```
base x+: contact at +0.032 mm
base x-: +0.056 mm, along +1.704 N
base y+: +0.044 mm, along +7.930 N  ->  8.11 N abort
```

0.05 mm 안에서 8 N. 그 자리에는 잴 것이 없다는 뜻이고, 그래서 높이를
바꿔가며 재는 스윕(`probe.heights_mm`)을 붙였다. 그런데 **첫 이동이
바로 답이었다**:

```
to +3.00 mm: TCP Jog: dy=-0.100mm
  to +3.00 mm: +0.101 mm, along -5.003 N, lateral 1.186 N
```

위로 0.1 mm 올렸더니 5.00 N이 **풀렸다**. 부호가 이동 방향의 반대이고
(누르던 힘이 사라지는 쪽), 0.1 mm 만에 거의 전부 사라진다. 즉 티칭된
착좌 자세는 퍽이 시트 바닥에 닿은 지점보다 **약 0.1 mm 더 내려가
있고**, 팔은 그 차이를 5 N으로 밀고 있다. 50 N/mm — 금속 대 금속의
강성이다.

이것이 §16.6부터의 가로 브래킷을 다시 읽게 만든다. 5 N으로 눌린 퍽은
마찰(µ·5 N)로 붙잡혀 있으므로, 꽉 문 채 옆으로 민 ±0.04 mm는 **보어
벽이 아니라 바닥 마찰**이다. 파지를 푼 §16.8의 벽들도 같은 하중 아래
있었다. "착지에서는 여유가 없고 살짝 들면 좌우가 열린다"는 예측은
이 예압으로 설명된다.

작업 항목 둘:

- 티칭 자세의 z를 0.1 mm 올릴 후보가 생겼다. 다만 5 N이 어느 스텝에서
  들어갔는지(스텝 3의 하강인지 스텝 4의 파지인지)는 아직 안 갈랐다.
- 예압 해제는 접촉과 **구분되지 않는다** — 크기도 방향도 같다. 그래서
  높이를 바꾸는 이동은 접촉 임계값을 아예 갖지 않는다(`StopAt::Travel`).
  막힘은 스텝이 실행되지 않는 것과 abort 힘, 두 가지로 남는다.

### 16.11 퍽은 똑바로 위로 나오지 않는다 (2026-08-18 실측)

§16.10의 이동에서 접촉 정지를 떼고 다시 3 mm를 올리자, 이번엔 세로가
아니라 **가로**에서 멈췄다:

```
to +3.00 mm: +0.084 mm, along -4.604 N, lateral 2.221 N
to +3.00 mm: +0.196 mm, along -4.947 N, lateral 2.668 N
to +3.00 mm: +0.316 mm, along -6.016 N, lateral 8.167 N   -> 10.14 N abort
```

`along`은 예상대로 5 N 근처에서 포화한다 — 예압은 0.2 mm면 다 풀린다.
그런데 `lateral`이 마지막 0.1 mm 스텝에서 2.7 → 8.2 N으로 뛴다. 순수
수직 이동인데 옆으로 5.5 N이 새로 생겼다는 것은 **퍽이 올라가면서 보어에
물린다**는 뜻이다. 팔의 수직과 보어 축이 일치하지 않거나, 퍽이 한쪽으로
치우쳐 앉아 있어 올라가는 길에 벽을 타는 것이다.

결과로 두 가지가 정해진다:

- 높이 사다리는 8 N abort 안에서 갈 수 있는 데까지만이다. 안전이 확인된
  마지막 지점은 +0.196 mm에서 5.62 N이라 `heights_mm: [0.2, 0.1, 0.0]`로
  좁혔다. "3 mm 들어서 재 본다"는 이 자세에서는 불가능하다.
- 실제 픽(스텝 5)도 같은 길을 지나간다. 시퀀스는 성공하지만 그건 서보가
  10 N을 밀고 지나가기 때문이지 길이 비어서가 아니다. 아직 안 잰 것:
  이 물림이 홀더 4에만 있는지, 열 자리 모두인지.

### 16.12 여섯 방향 전부 0.05 mm — 그리고 그게 시트라는 증거 (2026-08-18 실측)

한 방향이 abort해도 나머지를 계속 재도록 고친 뒤(`Probed::TooHard`)
티칭된 착좌 자세에서 꽉 문 채 여섯 방향을 다 얻었다:

| 방향 | 접촉 | 힘 |
|---|---|-----|
| base x+ | +0.039 mm | 트립 |
| base x− | −0.058 mm | 트립 |
| base y+ | +0.048 mm | 8.44 N (abort) |
| base y− | +0.050 mm | 7.60 N (abort) |
| base z− | +0.053 mm | 트립 |

방향에 무관하게 0.04–0.06 mm. 등방적이라 "보어 한쪽 벽"으로는 설명되지
않는다. 후보가 둘이었다 — 시트가 퍽을 사방에서 잡고 있거나, 팔이 무엇을
밀든 0.05 mm에서 접촉을 보고하거나.

**대조군이 갈랐다.** 스텝 5(`holder_above_return`, 퍽을 들어올린 자세)에서
멈추고 같은 프로브를 공중에서 돌렸다:

```
base x+: no contact within 3.00 mm     base y+: no contact within 3.00 mm
base x-: no contact within 3.00 mm     base y-: no contact within 3.00 mm
base z : floor at +3.932 mm from the force-versus-depth fit (tripped +4.071)
```

가로 네 방향 모두 3 mm를 끝까지 간다. 프로브는 멀쩡하고, 팔은 3 mm를
자유롭게 움직인다. 따라서 착좌 자세의 0.05 mm는 **시트가 퍽을 잡고 있는
것**이다 — 공칭 0.50 mm 반경 틈새는 티칭된 깊이에서 퍽이 겪는 것이
아니다. 아래로 3.93 mm에서 바닥을 찾은 것은 적합 자체의 검증이기도 하다
(홀더 위 4 mm에서 시작했으니 맞는 자리다).

들어올리기는 **세 번 모두 같은 자리에서 물렸다**: +0.316 / +0.305 mm에서
가로 힘 8.17 / 7.60 N. 그 사이 세로는 5–7 N을 0.2 mm에 걸쳐 놓아준다.
x/y를 먼저 센터로 맞추라는 지적대로 해봤지만 옮길 것이 없었다 — x의
중점은 −0.009 mm로 프로브 스텝(0.05 mm)의 1/5이고, y는 양쪽 다 벽이라
중점이 없다.

정리하면 이 자세에서 퍽은 사방 0.05 mm 안에 잡혀 있고, 똑바로 위로는
0.3 mm까지만 나오며, 자유는 보어를 완전히 벗어난 뒤에야 생긴다. 다음에
답해야 할 것: 이 0.05 mm 구속이 홀더 4만의 것인지, 그리고 5 N 예압을
빼도록 티칭 z를 0.1 mm 올리면 구속이 풀리는지.

### 16.13 들어올리기의 base 성분, 그리고 공중 대조군 (2026-08-18 실측)

§16.11의 `lateral`은 크기라서 어느 축인지 말해주지 못한다. base 성분으로
찍도록 고치고 착좌 자세에서 꽉 문 채 +2 mm를 시도했다 (`lift_abort_n`
15 N):

| 올라간 높이 | base x | base y | base z |
|---|---|---|---|
| +0.098 mm | −0.38 N | −1.17 N | −4.10 N |
| +0.207 mm | −0.46 N | +3.22 N | −4.96 N |
| +0.299 mm | −1.34 N | +7.63 N | −4.83 N |
| +0.404 mm | −2.13 N | +11.54 N | −5.63 N |
| +0.499 mm | −2.49 N | +14.30 N | −6.58 N |

세로(base z)는 예압이 풀린 −5 N 근처에 머문다. 자라는 것은 **base y
하나**다: 0.4 mm에 걸쳐 −1.17 → +14.30 N, 약 30 N/mm. base x는 같은
구간에서 −2.5 N까지밖에 안 간다. 15.94 N에서 abort.

팔이 옆으로 새서 그런 것이 아니다. 같은 스텝들의 지령선 밖 이동(drift)은
전부 0.018 mm 이하이고, 툴 회전(twist)은 0.4 mrad 이하다 — TCP는 보낸
직선 위에 있고 자세도 그대로인데 힘만 자란다. 즉 무언가가 퍽을 base y로
밀고 있고, 팔은 그것을 이겨내며 올라가는 중이다.

**공중 대조군.** 스텝 5에서 멈춰 퍽을 든 채(보어 밖) 같은 +2 mm를 같은
프로브 스텝으로 올렸다: 20 스텝 전부 base 세 축 모두 |0.14| N 이하,
drift 0.053 mm 이하, twist 0.38 mrad 이하로 +2 mm를 끝까지 간다. 그
높이에서 가로 브래킷도 양방향 3 mm에 아무것도 없다. 그러니 14 N은 팔의
컴플라이언스도 서보 아티팩트도 아니고, 시트/보어의 반작용이다.

따라서 **높이를 올린 뒤 재는 것은 그 힘을 없앤 다음이라야 뜻이 있다.**
14 N을 실은 채 잰 브래킷은 구멍이 아니라 그 하중 아래 팔이 얼마나
휘는지를 재는 것이다. 올라가는 도중 스텝마다 멈춰서 힘이 미는 쪽으로
0.05 mm씩 양보하고, 두 축 모두 `centring.settled_n` 아래로 내려온 뒤에야
다음 스텝을 밟는다(`Motion::climb_centred`). 기준 렌치는 첫 스텝 직전에
한 번만 잡는다 — 없애려는 것은 마지막 증분이 아니라 올라오면서 쌓인
하중 전체이기 때문이다.

물러설 곳의 한계도 정해져 있다. 팔이 실제로 실행하는 최소 스텝은
0.05 mm(§16.4)이고 이 방향의 강성이 30 N/mm이므로 한 스텝은 1.5 N이다.
그보다 낮은 값은 스텝을 아무리 많이 밟아도 도달할 수 없다. 그래서 두 번
연속으로 힘이 줄지 않으면 거기가 이 장비의 최소이고, 남은 하중을 그
레벨과 함께 기록한 채 계속 올라간다("arrived carrying (x, y, z) N").
반대로 옆으로 쓴 거리가 `centring.travel_mm`를 넘으면 그건 센터링이
아니라 끌려가는 것이므로 실패로 세운다. 배정량은 **경로 길이**로 센다 —
왕복 진동은 순 변위를 늘리지 않으므로 순 변위로 재면 영영 끝나지 않는다.

### 16.14 틸트 스캔 — 퍽은 기울어진 채 물려 있다 (2026-08-18 실측)

젠틀 그립(70 N/20 % 속도, §16.15 예정) + 시트 +0.15 mm에서 세 base 축
둘레로 ±0.3°를 0.05° 스텝으로 돌렸다(`Motion::tilt_scan`, TCP 중심 회전,
`probe_twist`). 착좌 레벨:

| 축 | + 방향 | − 방향 | Nm/deg (+/−) |
|----|---|---|---|
| base x | 0.30° 완주, 0.252 Nm | **−0.05°에서 0.386 Nm 정지** | 0.84 / **7.72** |
| base y | 0.25°에서 정지 | 0.25°에서 정지 | 0.73 / 1.35 |
| base z | 완주 | 완주 | 0.40 / 0.96 |

base x 둘레가 아홉 배 비대칭이다: −쪽은 사실상 강체(한 스텝에 정지),
+쪽은 부드럽다. 티칭된 자세가 퍽을 한쪽으로 피치 기울여 물고 있고, 그
기움이 시트에 눌려 있다는 뜻이다. +2 mm에서는 여섯 방향 모두 완주
(0.4–0.8 Nm/deg) — 구속은 시트 깊이에서만 강하다.

같은 런에서 젠틀 그립은 착좌 y± 충돌력을 7.26/7.83 → 5.06/5.70 N으로
낮췄고, +0.5 mm 등반은 (−2.7, −1.6, +2.5) N만 지고 도착했다(보정 없는
등반은 +0.3 mm에 8 N). 변하지 않은 것: y 구속 ±0.05 mm는 +2 mm까지
유지되고 바닥은 모든 레벨에서 0.07 mm 아래에 걸린다 — 퍽이 2 mm에서도
보어에 깊이 물려 있다는 쪽이 유력하다(진짜 픽이 퍽을 들고 나온다는 것은
§16.13의 free-air 바닥 +3.9 mm가 증명).

다음 실험: 잡기 자세 자체를 base x 둘레 +0.3° 돌려서
(`holder_on_position_tilt_x_deg`, TCP 중심이라 파지점 불변) 같은 측정 —
기움이 원인이면 착좌 y 5 N이 떨어져야 한다.

### 16.15 +0.3° 틸트 보정 — 5 N 핀치의 원인 확정 (2026-08-18 실측)

`holder_on_position_tilt_x_deg: 0.3`으로 잡기 자세를 파지점 중심으로
돌리고(§16.14의 처방) 같은 측정을 반복했다. 착좌 레벨:

| 항목 | 보정 전 | 보정 후 |
|---|---|---|
| base y 브래킷 | 양방향 5.06/5.70 N abort, 중점 없음 | **+0.048/−0.051 mm, 0.5 N 접촉** |
| base x 브래킷 | +0.039/−0.066 | +0.040/−0.064 (불변) |
| tilt base x 비대칭 | 0.84 / **7.72** Nm/deg | 0.62 / 0.56 (대칭) |
| +2 mm 도착 잔류 y | +8.60 N | **+0.09 N** |
| +2 mm base y 여유 | ±0.05 mm (물림) | **±0.151 mm** |

티칭된 파지 피치가 다섯 라운드 내내 본 착좌 y 5–8 N 하중의 뿌리였다.
보정 후 착좌 브래킷은 처음으로 양축 모두 실제 보어 여유(±0.05 mm)를
0.5 N 접촉으로 잰다. +2 mm에서 y 여유가 세 배로 열리는 것은 퍽이 이제
실제로 딸려 올라온다는 뜻이다(전에는 패드가 미끄러지거나 물려서 ±0.05
그대로였다).

남은 것 둘. (1) 보정 후 모든 레벨이 약하게 "softer toward −"라 최적
각도는 +0.3°보다 약간 작을 수 있다(하중 1–2 N 수준이라 시급하지 않음).
(2) 바닥은 여전히 +2 mm 레벨에서도 0.109 mm 아래에 걸린다 — 1 N
문턱의 이 트립이 시트 바닥인지 보어 옆면 마찰인지 미구분.

이 파라미터는 taught 파일에 있으므로 트리거마다 리로드된다 — 각도
튜닝에 데몬 재시작이 필요 없다.

### 16.16 홀더 2 검증 — 공유 +0.3°의 전이 (2026-08-18 실측)

같은 taught 자세(전 홀더 공유 회전 + 30 mm 수직 오프셋)와 같은
`holder_on_position_tilt_x_deg: 0.3`으로 홀더 2를 측정했다. 결과는
"대부분 전이, 시트만 잔여":

| 항목 | holder 4 (보정 후) | holder 2 |
|---|---|---|
| 시트 base x | ±0.05 브래킷 | +0.020/−0.058, 센터 −0.019 mm |
| 시트 base y | +0.048/−0.051, 0.5 N | **y− 5.19 N abort** (한계 5.00) |
| +0.5/+2.0 브래킷 | 양축 | 양축 클린, 센터 ≤0.013 mm |
| +2 mm 도착 잔류 | y +0.09 N | (−0.36, +2.68, −1.05) N |
| 등반 옆걸음 | 거의 없음 | −y로 0.3 + 0.9 mm |
| 시트 tilt x | 0.62/0.56 대칭 | 0.659/0.894, +0.25°에서 5.03 N stop |

보정 전 holder 4가 어느 레벨에서도 못 열던 y 브래킷이 홀더 2에서는
높이 레벨 전부 열린다 — 공유 보정이 핵심을 전달한다는 뜻. 남은 것은
시트 한정: y−가 0.19 N 차이로 한계를 넘고, 등반이 −y로 0.9 mm
걸어가며, tilt x가 +방향 force-stop — 홀더 2의 최적 각도/센터가
공유값과 미세하게 다르다. 현재 구조는 각도가 전 홀더 공유라 홀더별
값이 필요하면 waypoints 구조 변경이 필요하다.

이 런의 복귀 단계는 `return_to_trigger`의 f64::EPSILON 0 판정이
등반 옆걸음의 교차성분 잔여(≤0.012 mm)를 이동으로 오판해 0.000 mm
스텝을 명령, step-taken 가드로 죽었다. `MIN_EXECUTABLE_MM = 0.02`
실행 플로어(probe_reposition 소유, 컴파일 타임 분리 단언)로 수정.

### 16.17 홀더 2 y− 핀치 반증 — 4연속 클린 브래킷 (2026-08-18 실측)

64b3ef0 커밋 메시지는 홀더 2의 시트 y− 핀치(5.1–5.6 N)가 "두 배치와
0.3/0.4° 모두에서 불변이므로 그 보어의 물리적 특징"이라고 적었다.
피치 배치 복원을 배포한 직후부터의 시트 프로브가 이를 반증한다 —
같은 자리에서 y 브래킷이 4연속 클린, 5 N을 넘는 y− 접촉 전무:

| 시각 | base y 브래킷 | 센터 |
|---|---|---|
| 18:26 | +0.047/−0.053 mm | −0.003 mm |
| 18:27 | +0.052/−0.049 mm | +0.002 mm |
| 18:29 | +0.054/−0.056 mm | −0.001 mm |
| 20:24 (HolderMap 검증런) | +0.046/−0.053 mm | −0.004 mm |

"불변"의 근거였던 §16.16의 y− 5.19 N은 한계(5.00 N) 대비 0.19 N —
문턱 경계값이다. 반증만 확정이고 원인은 미구분 둘: (1) 경계 트립의
확률적 재현 실패, (2) §16.16 측정과 위 측정 사이에 들어간 잡기 명령
수정(6983b2d — "다시, 부드럽게" 재파지가 dedup에 막히지 않고 실제로
전달됨)이 시트에서의 유효 파지를 바꿨을 가능성. 어느 쪽이든 홀더 2의
시트는 공유 +0.3° 피치 배치에서 양축 모두 정상 여유(±0.05 mm)를
잰다. 커밋의 코드 변경(회전 후 평행이동)은 이 측정들과 부합하며,
틀린 것은 메시지의 "물리적 특징" 인과 주장뿐이다.

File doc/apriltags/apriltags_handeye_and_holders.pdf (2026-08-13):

# AprilTag 36h11 - hand-eye target (100 mm)

Print at 100% / actual size. Do NOT use 'fit to page' or 'shrink to fit'.

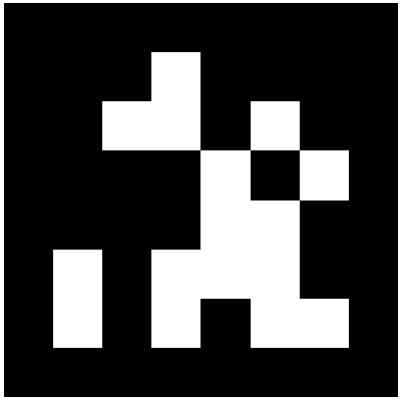
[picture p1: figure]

0 | 100 mm

<- must measure exactly 100 mm. If not, the print was scaled.

id = 0

100.0 mm

HAND-EYE / BASE
Hand-eye calibration target. Fix it to the floor or table so it cannot move while the arm is moved through calibration poses.
- The black border is part of the tag: 100.0 mm is the OUTER black square.
- Keep the white margin around it clear (>= 12.5 mm).
- Mount it flat. A bulge of 1 mm over 100 mm is already 0.6 deg of pose error.
- D405 at 300 mm sees this as ~225 px across: plenty for pose.

# AprilTag 36h11 - holder tags (10 mm)

Print at 100% / actual size. Cut along the dashed line to keep the quiet zone.

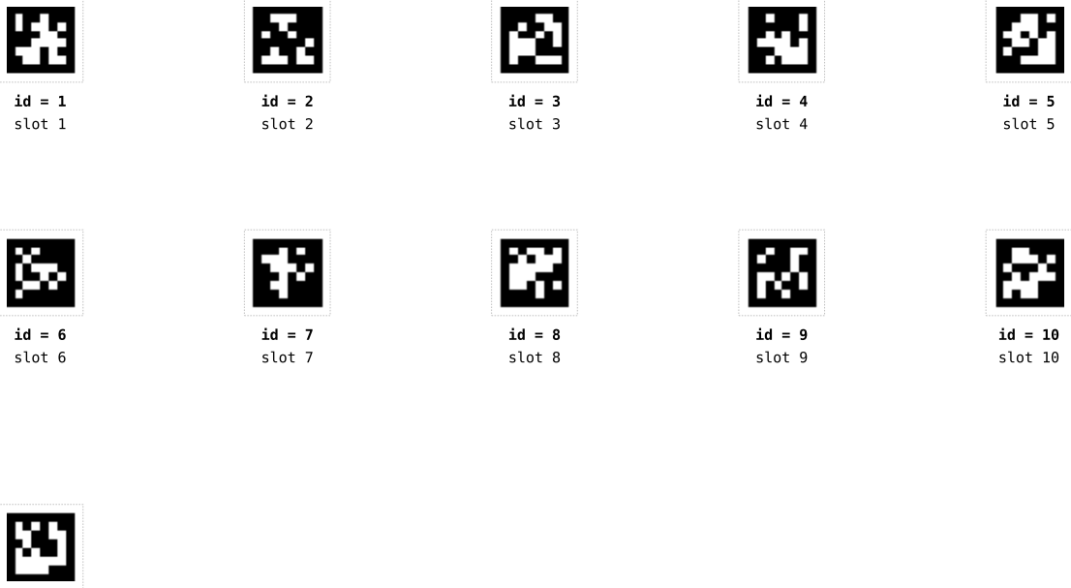
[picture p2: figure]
slot 1; slot 2; slot 3; slot 4; slot 5; slot 6; slot 7; slot 8; slot 9; slot 10

id = 11

MEAS.

HOLDER

Rack slot tags (id 1-10) and the measurement holder tag (id 11), 10.0 mm. Every tag carries a distinct id, so a detection identifies which holder it is.

10 mm is usable from 70 to ~150 mm only (96 px down to 45 px on a D405). Beyond ~200 mm detection becomes unreliable and pose is unusable.
That is fine for close-up localization; it is NOT enough for hand-eye, which is why the 100 mm tag on page 1 exists.

Each cell is 1.25 mm. Print on a 600 dpi laser printer or better;
inkjet bleed rounds the corners and biases the detected pose.
Matte paper. Glossy or laminated surfaces blow out under the D405 projector.

# AprilTag 36h11 - size trial strip

Print at 100% / actual size. Use this to choose the holder tag size empirically.

id = 100

10 mm

id = 101

15 mm

id = 102

20 mm

id = 103

25 mm

id = 104

30 mm

Trial strip. Before committing to 10 mm, tape these where a holder tag would go and check at the distance the wrist camera actually observes from.

Expected pixel size on a D405 (fx ~674 px):

dist | 10mm | 15mm | 20mm | 25mm | 30mm

-------+-----------------------------------
70mm | | 96 | 144 | 193 | 241 | 289
100mm | | 67 | 101 | 135 | 169 | 202
150mm | | 45 | 67 | 90 | 112 | 135
200mm | | 34 | 51 | 67 | 84 | 101
300mm | | 22 | 34 | 45 | 56 | 67

Rule of thumb: >= 30 px to detect, >= 60 px before trusting the pose. Pick the smallest size that still clears 60 px at your working distance.

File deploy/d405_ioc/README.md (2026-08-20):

# D405 camera IOC

epics-rs-iocs의 `d435i-ioc`를 Intel RealSense **D405** 한 대에 물려 돌리는
배치 파일 모음입니다. IOC 코드 자체(드라이버, st.cmd, 레코드 템플릿)는
`~/work/epics-rs-iocs`에 있고, 여기 있는 것은 **이 워크스테이션에서 굴리는
데 필요한 것들** — systemd 유닛, 수동 실행 스크립트, 호스트 준비 스크립트입니다.

`RS405:` prefix로 컬러·깊이를 pvAccess로 내보냅니다. 데스크톱 런처
`[1] Camera IOC`가 이 유닛을 띄웁니다.

## 구성

| 파일 | 용도 |
|---|---|
| `d405-ioc.service` | systemd **유저** 유닛. procServ 경유, 콘솔 20003 |
| `run-d405-ioc.sh` | systemd 없이 손으로 띄울 때 |
| `run-d435i-ioc.sh` | D435i용. 지금 그 카메라는 쓰지 않음 |
| `run-camera-viewer.sh` | PyDM 뷰어. 현재는 rsdm(PVA)를 쓰므로 비주력 |
| `install-librealsense.sh` | librealsense2 SDK 설치 (호스트 1회) |
| `reset-usb-controller.sh` | USB가 먹통일 때 xHCI 컨트롤러 리셋 |

## systemd (유저 레벨, sudo 없음)

```bash
cp d405-ioc.service ~/.config/systemd/user/
systemctl --user daemon-reload
systemctl --user enable --now d405-ioc
# 콘솔: telnet localhost 20003  (robot_ioc 20001, ur_monitor_ioc 20002)
# 로그:  journalctl --user -u d405-ioc -f
```

로그아웃해도 떠 있게 하려면 한 번만: `sudo loginctl enable-linger bl9b`

### 종료는 반드시 systemctl로

```bash
systemctl --user stop d405-ioc
```

유닛의 `ExecStop`이 **취득을 먼저 멈춥니다.** 스트리밍 중에 IOC를 강제
종료하면 RealSense 펌웨어가 물려서, USB 열거는 계속 되는데 프레임만 안
나오는 상태가 됩니다. USB 버스 리셋으로는 안 풀립니다(VBUS가 안 끊겨
카메라 ASIC 상태가 유지됨) — 실제로 한 대는 xHCI 컨트롤러 리셋까지, 다른
한 대는 물리적 재연결까지 갔습니다.

## 호스트 준비 (새 머신에서 1회)

```bash
sudo ./install-librealsense.sh
```

librealsense2는 Ubuntu 아카이브에 없고, 벤더 저장소(`librealsense.realsenseai.com`,
구 `librealsense.intel.com`)는 2026-08 기준 **InRelease 서명이 깨져 있어**
`apt update`가 저장소를 거부합니다. 같은 Release에 대한 분리 서명
`Release.gpg`는 정상이므로 콘텐츠는 진짜이고, Artifactory가 만든 InRelease만
망가진 상태입니다. 그래서 이 스크립트는 apt 저장소를 추가하는 대신
`Release.gpg → Release → Packages → *.deb` 서명 사슬을 직접 검증해 받은
`.deb`을 설치합니다.

받아둔 `.deb`은 저장소에 넣지 않았습니다(8 MB). 기본 경로는
`~/work/librealsense-debs/`이고, 없으면 스크립트 주석의 절차대로 다시
받으면 됩니다. 버전은 `Cargo.lock`의 `realsense-sys`(현재 2.56.5)에 맞춰
고정(`apt-mark hold`)합니다 — FFI 구조체가 그 헤더로 생성돼 있습니다.

## 설정 지속성

카메라 설정과 플러그인 활성 상태는 autosave가 들고 있습니다
(`epics-rs-iocs/iocs/d435i-ioc/auto_settings.req`, 저장 위치는
`iocs/d435i-ioc/autosave/RS405/`, 30초 주기). 재시작하면 스트림 모드와 PVA
플러그인이 그대로 복원됩니다.

`RSStreamMode`만 예외입니다. pass1 복원이 레코드 VAL은 채우지만 처리하지
않아 드라이버까지 값이 내려가지 않습니다 — `RSStreamMode`는 복원값을,
`RSStreamMode_RBV`는 드라이버 기본값을 가리키고 카메라는 후자로 돕니다.
st.cmd 안에서는 고칠 수 없습니다(프레임워크가 스크립트 종료 *후*에 복원을
실행). 그래서 유닛의 `ExecStartPost`와 `run-d405-ioc.sh`가 기동 후 한 번
강제로 처리합니다.

## USB 문제가 잦습니다

이 호스트에서 두 카메라 모두 SuperSpeed 링크가 끊긴 이력이 있습니다.
증상은 세 가지로 나뉩니다:

- **USB2로 강등** — `lsusb`상 480M, 커널에 `-75`(EOVERFLOW). 대역이 모자라
  프레임이 0. 케이블 교체가 유효했습니다.
- **재열거 후 무응답** — 링크는 SuperSpeed인데 커널에 `-32`(EPIPE). IOC가
  `try_wait_for_frames cannot be called before start()`로 반복합니다.
  드라이버가 장치 재열거를 복구하지 못하는 알려진 한계라, 지금은 서비스
  재시작이 가장 빠릅니다.
- **버스에서 소실** — `error -71`, 열거 자체 실패. `reset-usb-controller.sh`가
  풀어줄 때가 있고, 안 되면 물리적 재연결뿐입니다(VBUS 차단 불가).

과전류 로그는 한 번도 없었으므로 전원 부족은 아닙니다. 대역폭도 아닙니다 —
두 카메라 1280x720@30 동시 스트리밍을 무결점으로 통과했습니다.

## 성능 메모

PVA 이미지 서빙은 `epics-pva-rs`의 NTNDArray 변환이 픽셀마다 24바이트 enum을
만들던 탓에 640x480@15fps에서 CPU 1.5코어를 먹었습니다. 타입드 배열
(`ScalarArrayTyped`, `Arc<[T]>` + 벌크 memcpy)로 바꿔 9.5배 줄였고, 쓰지 않는
CA 경로(`CC1`/`image1`/`image2`)를 끄면 최종 17%입니다. 이 수정은 epics-rs
쪽에 있으며 릴리스 전까지는 `epics-rs-iocs/Cargo.toml`의 로컬
`[patch.crates-io]`로 물려 씁니다 — 그 patch는 커밋하지 마세요.

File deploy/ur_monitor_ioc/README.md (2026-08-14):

# UR monitoring IOC (read-only)

epics-rs-iocs의 ur-robot IOC(urRobot 포트)에서 **dashboard + RTDE
receive** 두 포트만 로드하는 감시 전용 IOC입니다. `Robot:UR:` prefix로
로봇 모드/안전 상태/조인트·TCP 상태를 CA로 노출합니다.

control / io / jog / gripper db는 의도적으로 뺐습니다 — 해당 포트들은
프로그램 슬롯, RTDE 입력 레지스터, URCap 그리퍼 소켓에 **씁니다**.
robot-sequencer(ur-driver + robotiq-hande)가 그 셋을 쥐고 있습니다.

읽기는 배타적이지 않습니다. 데몬이 자기 RTDE 스트림을 물고 있는 상태에서
두 번째 RTDE 클라이언트가 자기 출력 레시피로 125 Hz를 받고, 대시보드
29999도 동시 접속 2개가 모두 `robotmode`에 답하는 것을 실측했습니다
(URControl 5.16.0.0). 그래서 이 IOC는 시퀀서와 동시에 떠 있어도 됩니다.

## 빌드/실행

epics-rs-iocs 체크아웃은 이 호스트에서 `~/work/epics-rs-iocs`입니다
(`~/epics-rs-iocs`는 없습니다).

```bash
cd ~/work/epics-rs-iocs && cargo build --release -p ur-robot-ioc
# 수동 실행:
~/work/epics-rs-iocs/target/release/ur-robot-ioc \
    ~/work/robot-sample-changer/deploy/ur_monitor_ioc/st.cmd
```

## systemd (유저 레벨, sudo 없음)

```bash
mkdir -p ~/.config/systemd/user
cp ur-monitor-ioc.service ~/.config/systemd/user/
systemctl --user daemon-reload
systemctl --user enable --now ur-monitor-ioc
loginctl enable-linger bl9b   # 로그아웃/부팅 후에도 유지 (1회)
# 콘솔: telnet localhost 20002  (robot_ioc는 20001)
# 로그:  journalctl --user -u ur-monitor-ioc -f
```

읽기 전용이고 20002/5064만 쓰므로 시스템 유닛일 이유가 없습니다. linger를
켜지 않으면 로그아웃할 때 세션과 함께 내려갑니다.

URSim 리허설 시에는 st.cmd의 `IP`를 192.168.56.101로 바꿔서 수동 실행.

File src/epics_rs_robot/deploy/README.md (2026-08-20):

# robot_ioc — procServ + systemd(유저) 부팅 자동시작

`robot_ioc`(EPICS soft IOC)를 procServ 아래에서 데몬으로 돌리고 systemd로 부팅 시
자동 시작합니다. procServ가 iocsh 콘솔을 TCP 20001(localhost 전용)로 노출하므로,
실행 중인 IOC에 붙어서 `dbl`, `camonitor` 등 iocsh 명령을 쓸 수 있습니다.

## 1. release 바이너리 빌드 (서비스가 참조)

```bash
export PATH="$HOME/.cargo/bin:$PATH"
cd ~/ws/src/epics_rs_robot && cargo build --release -p robot_ioc
```

## 2. 설치 & 활성화 (**유저 유닛**, sudo 없음)

먼저 수동으로 돌던 IOC가 있으면 정지:
```bash
pkill -x robot_ioc
```

유닛 설치 → 부팅 자동시작 등록 → 지금 시작. **이 저장소의 사본을 설치하세요** —
`~/ws/src/epics_rs_robot/deploy/`에 남아 있는 구 트리 사본은 `ROBOT_DB`가
`~/ws/db`를 가리키고, 그 db에는 CalibMode 3-7 라벨도 `Robot:MapSource`도
없습니다(그립 널·홀더 간 이동이 쓰는 PV):
```bash
install -m 644 ~/work/robot-sample-changer/src/epics_rs_robot/deploy/robot-ioc.service \
     ~/.config/systemd/user/robot-ioc.service
systemctl --user daemon-reload
systemctl --user enable --now robot-ioc.service
```

이 호스트의 다른 IOC 둘(`ur-monitor-ioc`, `d405-ioc`)과 같은 유저 유닛입니다.
root가 필요한 항목이 하나도 없어서입니다 — TCP 20001도 CA 5064도 비특권
포트이고 경로는 전부 `/home/bl9b` 아래입니다. sudo를 뗀 값은 데스크톱
런처(`[0] Robot IOC`)가 IOC를 직접 띄울 수 있다는 것입니다.

로그인 없이도 유지되려면 linger가 켜져 있어야 합니다(이 호스트는 이미 켜짐):
```bash
loginctl show-user "$USER" -p Linger      # Linger=yes
```

**구 시스템 유닛을 지우세요.** `/etc/systemd/system/robot-ioc.service`에 2026-06-01
사본이 남아 있으면 같은 이름이 시스템·유저 양쪽에 존재하고, 그 사본은
`ROBOT_DB=~/ws/db`를 들고 있습니다. 지우는 것만 sudo가 필요합니다:
```bash
sudo systemctl disable --now robot-ioc.service      # 시스템 쪽
sudo rm /etc/systemd/system/robot-ioc.service
sudo systemctl daemon-reload
```

## 3. 상태 / 로그 / 제어

```bash
systemctl --user status robot-ioc.service
journalctl --user -u robot-ioc.service -f   # systemd 레벨 로그
tail -f ~/ws/src/epics_rs_robot/robot_ioc/ioc/procServ.log   # IOC 콘솔 출력

systemctl --user restart robot-ioc.service
systemctl --user stop robot-ioc.service
```

## 4. 실행 중 IOC의 iocsh 콘솔 붙기/나가기

```bash
telnet localhost 20001      # 또는: nc localhost 20001
# iocsh 프롬프트에서: dbl / camonitor Robot:CurrentStep / 등
# 나가기(IOC는 계속 실행): Ctrl-] 입력 후 'quit'  (telnet escape)
```

procServ 콘솔에서 `Ctrl-X` = IOC 자식 프로세스 재시작(restart), `Ctrl-T` = autorestart 토글.
`--ignore "^D^C"` 로 Ctrl-D/Ctrl-C 는 무시되어 실수로 IOC가 죽지 않습니다.

## 동작 방식 / 복원력

- procServ가 IOC 자식이 죽으면 **자동 재시작**(holdoff 후). `systemd --user`는
  procServ 자체가 죽으면 **재시작**(`Restart=always`). → 2중 복원력.
- IOC가 재시작돼도 autosave(`robot_ioc/autosave/robot_state.sav`)가 Robot:CurrentStep 등
  상태를 복원하므로, 크래시 후 재개 흐름이 그대로 유지됩니다 (CLAUDE.md 참고).

## 참고: 브리지(epics_ros_bridge)

브리지는 iocsh가 아니라 ROS2 노드라 procServ를 쓰지 않습니다. 부팅 자동시작이 필요하면
ROS 환경을 source 하는 별도 systemd 유닛으로 구성할 수 있습니다(요청 시 추가).

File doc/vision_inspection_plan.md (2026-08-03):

# 퍽 장착 검증 + 마커 기반 지그 로컬라이제이션 개발 계획

대상: UR3e + Hand-E 시료 교환기 (시료 랙 10슬롯 + 측정 홀더 1개)

**Rev 2** — 잦은 재설치 대응(마커 기반 캘리브레이션)과 그립 상태 머신을 반영.

해결하려는 문제:
1. **측정 홀더에 퍽이 이미 있는데 또 넣으려고 함** → 퍽끼리 충돌, protective stop
2. **퍽이 제대로 장착되지 않음** → 기울어짐 / 덜 들어감 / 그리퍼 후퇴 시 낙하
3. **헛파지** — 퍽을 못 잡은 채로 시퀀스가 계속 진행
4. **설치 위치가 계속 바뀜** → 재설치마다 10슬롯 재티칭이 필요한 현재 구조

---

## 0. 요약 — 결론 먼저

### 0.1 머신러닝은 필요 없다 (그리고 재설치가 잦다는 사실이 그 결론을 더 강화한다)

이 문제는 인식(recognition) 문제가 아니라 **측정(metrology) 문제**다. 퍽 형상이 하나로
고정돼 있고, 지그가 강체이며, 판정 기준을 mm/deg로 기술할 수 있다.

**재설치가 잦다는 조건은 ML에게 불리하고 기하 방식에게 유리하다** — 직관과 반대다:

| | 재설치 시 발생하는 일 | 복구 비용 |
|---|---|---|
| **ML** | 시점·배경·조명이 전부 바뀜 → 학습 분포 이탈 → 성능이 조용히 저하됨 (경고 없이) | 재수집 + 재학습 + 재검증, **재설치마다** |
| **기하 + 마커** | ROI와 기준 평면이 지그 프레임에 매달려 있으므로 자동으로 따라감. 판정량(Δz, θ)이 **지그 상대량**이라 설치 불변 | 마커 스캔 1회 (~1분) |

ML이 "환경 변화에 유연하다"는 통념은 **학습 분포 안에서의 변화**에 해당한다. 카메라가
통째로 다른 위치로 가는 것은 분포 밖 변화이고, ML은 여기서 가장 나쁘게 실패한다 —
틀렸다는 사실을 스스로 알리지 못한 채 틀린다.

ML의 유일한 잔여 니치는 **금속 반사로 인한 depth 드롭아웃**이고, 이건 Phase 0의 조명 개선으로
먼저 친다. 그래도 `UNKNOWN` 비율이 2%를 넘으면 그때 **정상 데이터만 쓰는 이상탐지**를 보조로
넣는다 (§3 참조). 지도학습 분류기는 끝까지 안 쓴다.

### 0.2 이미 시스템 안에 있는데 버려지고 있는 신호 3개

조사 결과, 필요한 신호의 상당수가 **이미 하드웨어에서 읽혀 소프트웨어까지 도달했다가
버려지고 있다.** 새로 만들 것이 아니라 배선만 하면 된다.

| 신호 | 현재 상태 | 근거 |
|---|---|---|
| **`gOBJ` (물체 검출)** | Hand-E가 하드웨어로 판정해서 Modbus로 보내고, 드라이버가 파싱까지 하는데 **ROS로 export 안 함** | `protocol_logic.hpp:56` 에 `ObjectDetectionStatus` 열거형 정의, `hande_hardware_interface.cpp:151` `export_state_interfaces()` 는 POSITION/VELOCITY만 내보냄 |
| **그리퍼 전류 (0–2.55 A)** | 동일하게 파싱만 하고 export 안 함 | `hande_gripper.hpp:139` `get_current()` |
| **손목 6축 힘/토크** | 컨트롤러가 `ft_data` 토픽으로 publish 중, **아무도 구독 안 함** | `ur_hande_controllers.yaml:74-86` (frame `tool0`) |
| 그리퍼 스트로크 연속값 | `/joint_states` 로 들어오는데 시퀀스가 **이진 open/close로 축약하고 버림** | `epics_triggered_sequence.cpp:1371` |

특히 **`gOBJ`가 결정적이다.** Robotiq 프로토콜의 `REQ_POS_NO_OBJECT`(=3)는
"요청 위치까지 다 닫혔는데 아무것도 안 걸렸다" = **헛파지 그 자체**를 하드웨어가 알려주는
값이다. `export_state_interfaces()` 에 두 줄 추가하면 얻는다.

### 0.3 재설치 대응의 진짜 병목은 마커가 아니라 웨이포인트 저장 형식이다

`taught_waypoints.yaml` 은 **관절각 절대값**을 저장한다:

```yaml
holder1_standby:     [7개 관절값]
holder1_on_position: [7개 관절값]
sample_holder_on_position: [7개 관절값]
holder_multi_x_offsets: [0.0003, 0.0005, 0.0015, 0.0015, 0.003, 0.003, 0.003, 0.003, 0.003]
holder_multi_z_offsets: [0.0, 0.0, 0.0, 0.0002, 0.00025, 0.0003, 0.00035, 0.0004, 0.00045]
```

지그가 1 mm라도 움직이면 이 값들이 전부 무효다. 마커를 붙여서 `T_base_rack`을 알아내도,
웨이포인트가 관절 절대값인 한 **그 정보를 쓸 곳이 없다.**

추가로, 위의 18개 오프셋 배열은 홀더 번호에 따라 **단조 증가**한다. 이건 랙의 기울기 또는
직각도 오차가 슬롯을 따라 누적되는 것을 슬롯마다 손으로 보정한 흔적이다. 지그 자세를
6-DoF로 한 번 피팅하면 이 18개가 **자세 파라미터 하나로 흡수된다.**

따라서 재설치 대응의 핵심 작업은 **관절 절대 티칭 → 지그 프레임 상대 포즈 + 런타임 IK**
리팩터다 (§5). 마커는 그 입력을 공급하는 수단이다.

---

## 1. 실패 모드 분해

| ID | 실패 모드 | 발생 지점 (step) | 관측량 | 1순위 센서 |
|----|---|---|---|---|
| F1 | 집으려는 랙 슬롯이 비어 있음 | 3–4 | 슬롯 ROI depth | 비전(점유) |
| F2 | **헛파지** | 4, 15 | `gOBJ`, 스트로크 | **gOBJ + 스트로크** |
| F3 | 이송 중 낙하 | 5–8, 16–19 | 스트로크 붕괴, `gOBJ` 변화 | **그리퍼 상태 감시** |
| F4 | **측정 홀더에 퍽이 이미 있음** | 9 | 홀더 ROI depth | 비전(점유) |
| F5 | 측정 홀더 안착 불량 | 10–11 | 상단면 Δz, 기울기 θ | 비전(안착) |
| F6 | 측정 후 측정 홀더가 비어 있음 | 13–14 | 홀더 ROI depth | 비전(점유) |
| F7 | 반환할 랙 슬롯이 이미 차 있음 | 20 | 슬롯 ROI depth | 비전(점유) |
| F8 | 랙 슬롯 안착 불량(홈 미체결) | 21–22 | Δz, θ, 중심 오프셋 | 비전(안착) |
| F9 | 삽입 중 이상 접촉 | 3, 9, 14, 20 | `ft_data` 힘 프로파일 | **FT 센서** |
| F10 | **재설치 후 지그 위치 불일치** | 전 구간 | 마커 포즈 vs 저장값 | **마커 로컬라이제이션** |

F2/F3/F9는 비전이 필요 없다. F10은 신규 — 재설치가 잦다는 조건에서 나온 실패 모드이고,
**검출되지 않으면 나머지 모든 대책이 무의미해진다** (지그 위치가 틀리면 ROI도 틀리다).

---

## 2. 그립 상태 머신 (비전 불필요, 최우선)

### 2.1 신호 결합

`gOBJ` 하나로는 부족하다. `gOBJ`는 "뭔가에 걸려서 멈췄다"를 말할 뿐, **"올바른 것에
걸렸다"** 를 말하지 않는다. 퍽을 비스듬히 물었거나 이물을 물어도 `gOBJ=2`가 나온다.
스트로크가 **치수**를 알려주므로 둘을 결합한다.

```
Robot:GraspState (mbbi)
  0 UNKNOWN    초기 / 그리퍼 통신 불가
  1 OPEN       열림 완료, 물체 없음
  2 EMPTY      닫힘 완료, 물체 미검출              ← 헛파지 (F2)
  3 HOLDING    닫힘 중 접촉 정지 + 스트로크 정상    ← 정상 파지
  4 MISGRIP    물체 검출됐으나 스트로크 이상        ← 비스듬히 물림 / 이물
  5 DROPPED    HOLDING → 스트로크 완전 폐쇄로 붕괴  ← 이송 중 낙하 (F3)
  6 FAULT      그리퍼 fault (gFLT)
```

판정 규칙:
```
gOBJ == REQ_POS_NO_OBJECT (3)                      → EMPTY
gOBJ == STOPPED_CLOSING_DETECTED (2)
    AND |stroke − stroke_puck| ≤ tol                → HOLDING
    AND 그 외                                        → MISGRIP
HOLDING 유지 중 stroke → stroke_closed 로 붕괴       → DROPPED
gFLT != 0                                          → FAULT
```

`stroke_puck` 은 퍽 파지 직경에서 결정된다 — **§9의 미확인 사항 1번이 확정돼야 값이 정해진다.**

### 2.2 보조 확증 (선택, 정확도 향상용)

- **그리퍼 전류 (`gCU`)**: 정상 파지 시 유지 전류가 안정적. 한계 파지는 전류가 떨어진다.
- **FT 차분**: 같은 포즈에서 파지 전/후 `ft_data`의 Δ|F| ≈ 퍽 무게.
  **반드시 차분으로 쓴다** — UR 내장 FT의 절대 정확도는 낮지만, 동일 포즈 차분은
  중력·툴하중·바이어스가 상쇄되어 분해능 한계까지 쓸 수 있다.
  (구체적 수치 한계는 UR3e 데이터시트로 확인 필요 — §9)

### 2.3 DROPPED는 체크포인트가 아니라 상시 감시

낙하는 언제든 일어난다. `HOLDING` 상태인 동안 ~10 Hz로 스트로크를 감시하는 백그라운드
모니터가 필요하다. 스텝 경계에서만 확인하면 낙하 후 여러 스텝을 헛돌게 된다.

### 2.4 필요한 코드 변경

1. `hande_hardware_interface.cpp:151` `export_state_interfaces()` 에
   `object_detection` / `current` 상태 인터페이스 추가 (드라이버가 이미 값을 갖고 있음)
2. 두 값을 publish 하는 broadcaster 추가 (또는 기존 그리퍼 상태 토픽 확장)
3. 그립 상태 머신 노드 → `Robot:GraspState`, `Robot:GripperPos`, `Robot:GripperCurrent`
4. 시퀀스에서 step 4/15 직후 `GraspState == HOLDING` 확인, 아니면 정지

**업스트림 영향**: `robotiq_hande_driver`는 외부 패키지다. 포크 수정 시 업스트림 diff를
최소로 유지하고, 변경 내역을 `doc/` 에 기록한다 (향후 업스트림 갱신 시 재적용해야 함).

---

## 3. 알고리듬 vs 머신러닝 (Rev 1에서 유지, 재설치 조건 반영)

### 3.1 점유 판정 (F1/F4/F6/F7)

판별 마진이 퍽 두께(수 mm~cm)라 SNR이 압도적. ROI depth median 하나로 결정된다.
필요 데이터는 빈/찬 상태 각 10~20 프레임. ML은 수백~수천 장을 쓰고 동등 이하 성능.
→ **논쟁 여지 없이 알고리듬.**

### 3.2 안착 품질 (F5/F8)

마진이 0.5~3 mm / 1~5°. 여기가 실제 판단 지점이다.

| 항목 | 기하 (평면 피팅) | 지도학습 CNN | 이상탐지 (one-class) |
|---|---|---|---|
| **실패 데이터 필요** | **불필요** | **필수 (200+)** | **불필요** |
| 정상 데이터 필요 | 10~30 프레임 | 500+ | 100~300 |
| 미학습 실패 모드 | **검출됨** (open-set) | **놓침** (closed-set) | 대체로 검출 |
| **재설치 후** | **자동 추종** (지그 프레임 상대) | **재수집·재학습** | 정상셋 재구축 |
| 출력 | Δz [mm], θ [deg] | 확률 | 이상 점수 + 히트맵 |
| 임계값 근거 | **기계 공차에서 유도** | 검증셋 튜닝 | 검증셋 튜닝 |
| 반사 강건성 | **낮음** | 높음 | 중간 |
| 개발 기간 | 3~4주 | 6~10주 + 수집기간 | 3~5주 |

지도학습을 배제하는 결정적 이유 두 가지:

1. **실패 데이터가 희소한 게 문제의 본질이다.** 가끔 일어나니까 문제인 것이다.
   200장을 모으려면 고의로 200번 잘못 꽂아야 하고, 고의 실패는 실제 실패와 분포가 다르다.
2. **안전 인터록에 closed-set 분류기를 쓰면 안 된다.** 학습에 없던 실패 모드는 높은 확률로
   "정상"으로 분류된다. 인터록의 요구사항은 "본 적 있는 불량을 잘 맞히기"가 아니라
   **"정상 아닌 것을 통과시키지 않기"** 다.

여기에 재설치 조건이 3번째 이유를 추가한다: **재설치마다 재학습은 운영 불가능하다.**

### 3.3 권고 구조

```
Layer 0  gOBJ + 스트로크 + 전류 + FT   → F2, F3, F9    (비용 ~0, 이미 배선됨)
Layer 1  마커 + depth 지그 로컬라이제이션 → F10          (재설치 대응의 기반)
Layer 2  기하/깊이 점유 판정             → F1,F4,F6,F7
Layer 3  기하/깊이 안착 판정             → F5, F8       (주력)
Layer 4  이상탐지 ML (조건부)            → Layer 3의 UNKNOWN·gray zone만
```

Layer 4는 **fail-safe 방향으로만** 작동한다:
- `OK` → `NG` 뒤집기 **가능** (더 보수적으로)
- `UNKNOWN` → `OK`/`NG` 해소 **가능**
- `NG` → `OK` 덮어쓰기 **불가능** — 런타임 `if`가 아니라 타입/API로 강제

---

## 4. 마커 기반 지그 로컬라이제이션

**확정 사항 (Rev 3): 외부 고정 카메라 1대 + AprilTag(tag36h11)를 쓴다.**
실무 설정·튜닝은 별도 문서 `doc/vision_camera_setup.md` 참조. 이 절은 구조만 다룬다.

### 4.1 세 종류의 마커를 구분한다 (혼동하면 안 됨)

기존 `hand_eye_calibration_node.py`는 **ArUco DICT_6X6_250 + solvePnP + `cv2.calibrateHandEye`**
로 eye-in-hand 캘리브레이션을 한다. 이건 세 용도 중 하나일 뿐이고, 아래 M1에만 해당한다.
M2/M3는 AprilTag로 새로 만든다 (기존 ArUco 코드를 고치는 것이 아니라 별도 경로).

| # | 역할 | 마커 위치 | 산출물 | 재실행 시점 |
|---|---|---|---|---|
| **M1** | Eye-in-hand (**기존 구현**) | 고정된 정지 마커 (ID 0) | `T_tool0_cam` | **손목 D405를 병용할 때만 필요.** 외부 카메라만 쓰면 **불필요** |
| **M2** | 지그 로컬라이제이션 (**신규**) | 랙에 3개 이상, 측정 홀더에 2개. **영구 부착** | `T_cam_rack`, `T_cam_measholder` | **재설치마다 (자동)** |
| **M3** | **Eye-to-hand 캘리브레이션 (신규, 필수 1회)** | 태그를 **그리퍼에** 임시 부착 | `T_base_cam` | **평생 1회.** 카메라를 물리적으로 건드렸을 때만 |
| **M4** | **자기 검증 (신규)** | **로봇 베이스에 영구 부착** | 드리프트 감지 | 매 측정 (자동) |

**M1(eye-in-hand)은 외부 카메라만 쓰면 불필요하다.** 손목에 카메라가 없으므로.
`§6.1`의 대안(손목 D405 병용)을 택할 때만 되살린다 — 이미 구현돼 있으니 재사용.

**하지만 카메라↔로봇 관계(`T_base_cam`)는 반드시 필요하다.** 카메라가 `T_cam_rack`을
알아내도 로봇 좌표로 옮기지 못하면 쓸 수 없다:

```
T_base_rack = T_base_cam · T_cam_rack
              ▲
              └── 이게 M3. 없으면 아무것도 안 됨
```

이건 eye-in-hand가 아니라 **eye-to-hand(eye-on-base)** 캘리브레이션이다. 이름이 비슷해
혼동하기 쉽지만 다른 것이다.

**핵심: `T_base_cam`은 평생 1회로 끝난다 — 카메라를 로봇과 같은 강체에 고정하는 조건에서.**

| 상황 | `T_base_cam` 변하나 | 재캘리브레이션 |
|---|---|---|
| 랙만 재설치 | 아니오 | **불필요** |
| 셀 전체를 다른 곳으로 이사 (로봇+카메라 함께) | 아니오 | **불필요** |
| 카메라 마운트를 건드림 / 렌즈·초점 변경 | 예 | 필요 |
| 로봇을 브레드보드에서 분리 | 예 | 필요 |

이것이 `vision_camera_setup.md` §1.4에서 카메라를 **벽·천장이 아니라 로봇과 같은
브레드보드에 직결**하라고 한 진짜 이유다. 진동 때문만이 아니라 **캘리브레이션 수명**
때문이다. 재설치가 아무리 잦아도 M3는 다시 하지 않는다.

**M3 절차 (기존 코드 재사용):**
```
1. 태그를 그리퍼에 붙인다 (임시)
2. 로봇을 10~20개 자세로 움직인다 — 위치뿐 아니라 회전도 충분히 다양하게
   (회전 다양성이 부족하면 calibrateHandEye 해가 불안정해진다)
3. 각 자세에서 카메라로 태그 관측 + /joint_states 기록
4. cv2.calibrateHandEye → T_base_cam
```
`hand_eye_calibration_node.py:463-467` 의 `invert_gripper2base: true` 가 정확히 이
역변환을 수행한다. **파라미터 전환 + 태그를 그리퍼에 부착 + 결과를 `T_base_cam` 으로
해석해 저장**하면 되고, 새 코드는 거의 필요 없다. 로봇 자신의 기구학이 자 역할을 하므로
외부 측정 도구가 필요 없다.

이 1회 작업에는 **AprilTag 포팅이 불필요하다** — 기존 ArUco 경로를 그대로 쓴다.
AprilTag는 매 사이클 읽는 M2/M4 지그 태그용이다.

**⚠ 기존 코드의 함정**: `hand_eye_calibration_node.py:80-85` 는 카메라 내부 파라미터가
**D405 값으로 하드코딩**돼 있고 `dist_coeffs = zeros(5)` 다 ("RealSense는 왜곡 보정된
이미지를 제공"이라는 주석). **새 외부 카메라에는 이게 틀리다.** 일반 산업용 카메라+렌즈는
실제 왜곡이 있고, 0으로 두면 화면 가장자리에서 수 mm 어긋난다. 새 카메라의 내부
파라미터를 실측해서 넣어야 한다 (`vision_camera_setup.md` §4.3).

**M4(로봇 베이스 태그)의 역할이 바뀐다.** 원래 계획에서는 `T_base_cam` 을 매번 구하는
필수 수단이었지만, M3가 1회로 끝나므로 **검증 장치**가 된다. 로봇 베이스에 영구
부착하고, 매 측정마다 `T_cam_M4` 를 저장값과 비교해 **카메라와 로봇의 관계가 틀어졌는지**
직접 감지한다. `vision_camera_setup.md` §5.1의 자기 검증 태그와 **같은 태그 하나로
통합**한다 — 브레드보드 임의 위치보다 로봇 베이스가 낫다. 지키고 싶은 관계를 정확히
감시하기 때문이다.
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

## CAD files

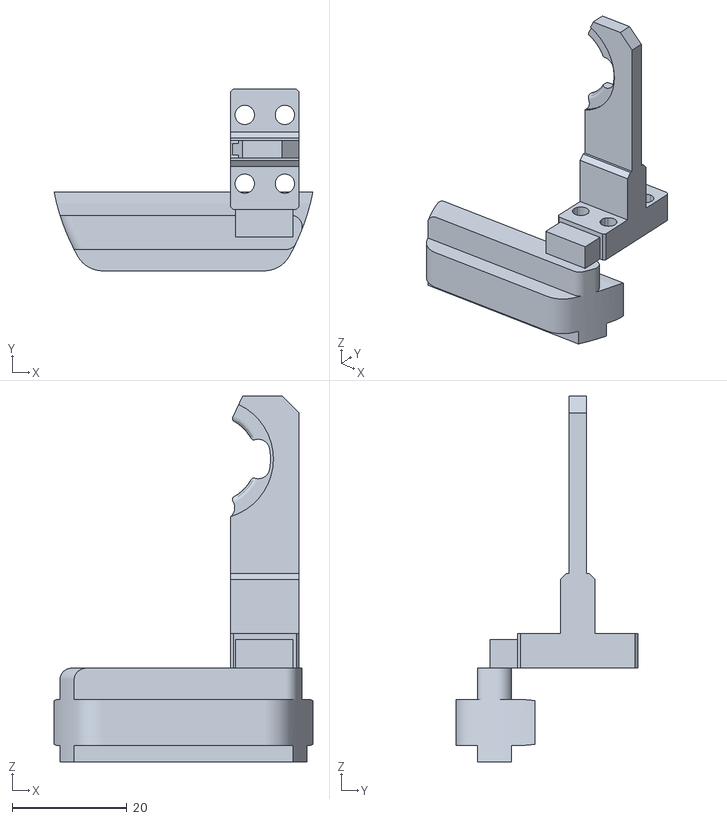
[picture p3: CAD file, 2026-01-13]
model/meshes/robotiq_hande_description/meshes/finger_assembly.stl
45.2 x 31.7 x 63.9

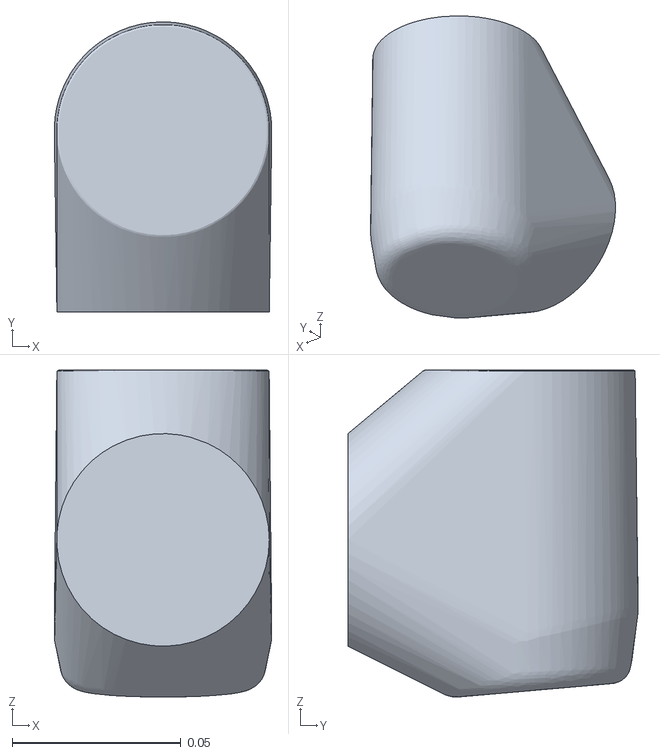
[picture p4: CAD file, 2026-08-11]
model/meshes/ur_description/meshes/ur3e/collision/wrist1.stl
0.0645 x 0.086 x 0.0969

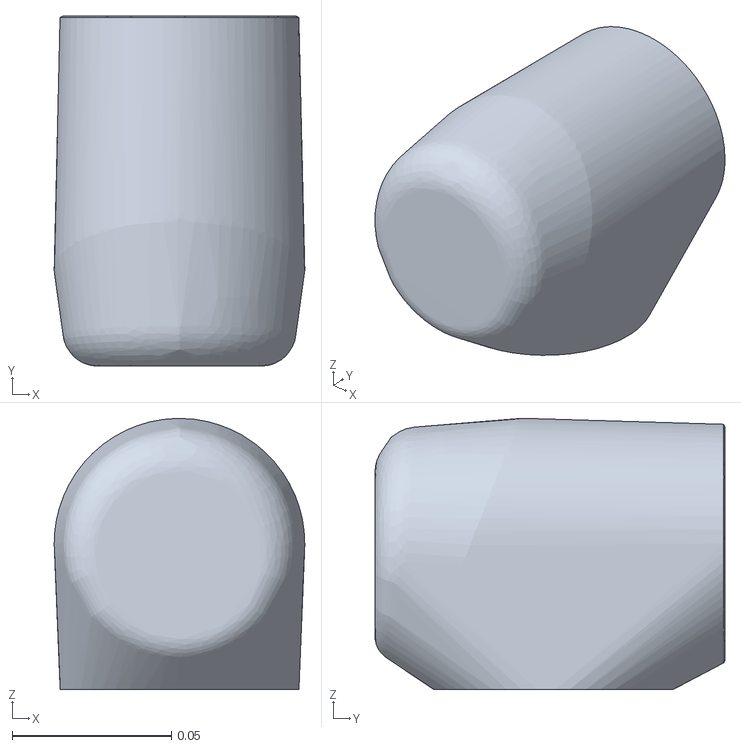
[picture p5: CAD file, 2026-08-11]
model/meshes/ur_description/meshes/ur5e/collision/wrist2.stl
0.0787 x 0.11 x 0.0852

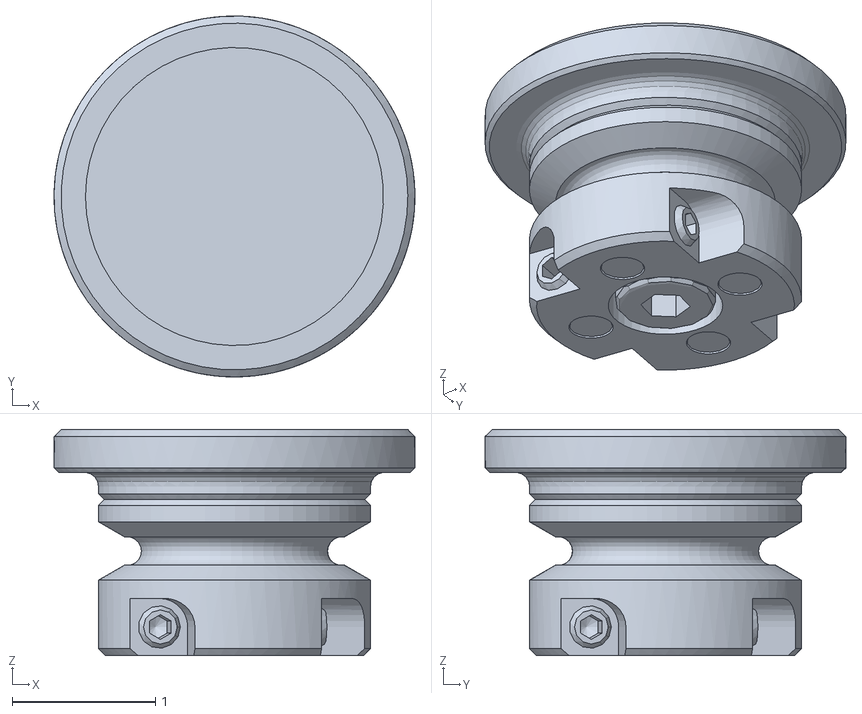
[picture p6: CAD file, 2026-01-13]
resources/holder.stl
2.52 x 2.52 x 1.58

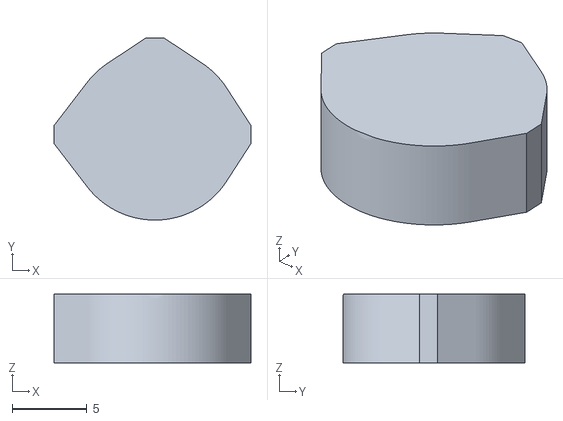
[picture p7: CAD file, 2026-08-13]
resources/stage_parts/stage_part27.stl
13.2 x 12.2 x 4.61

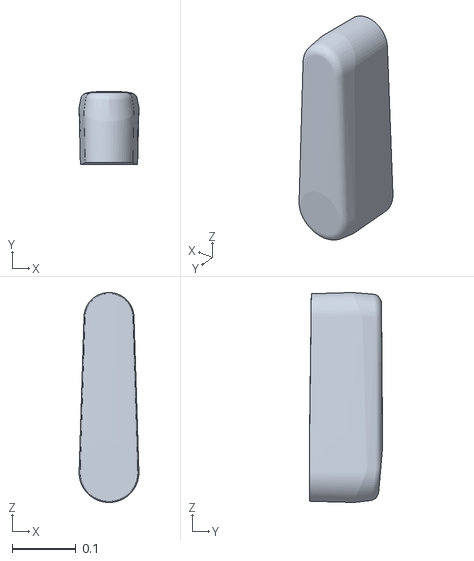
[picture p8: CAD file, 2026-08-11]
model/meshes/ur_description/meshes/ur3e/collision/upperarm.stl
0.094 x 0.115 x 0.33

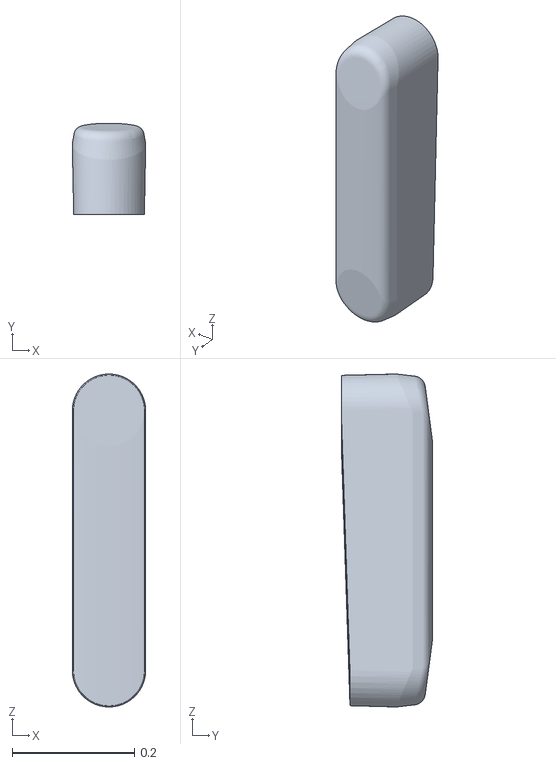
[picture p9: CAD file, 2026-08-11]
model/meshes/ur_description/meshes/ur5e/collision/upperarm.stl
0.12 x 0.15 x 0.545

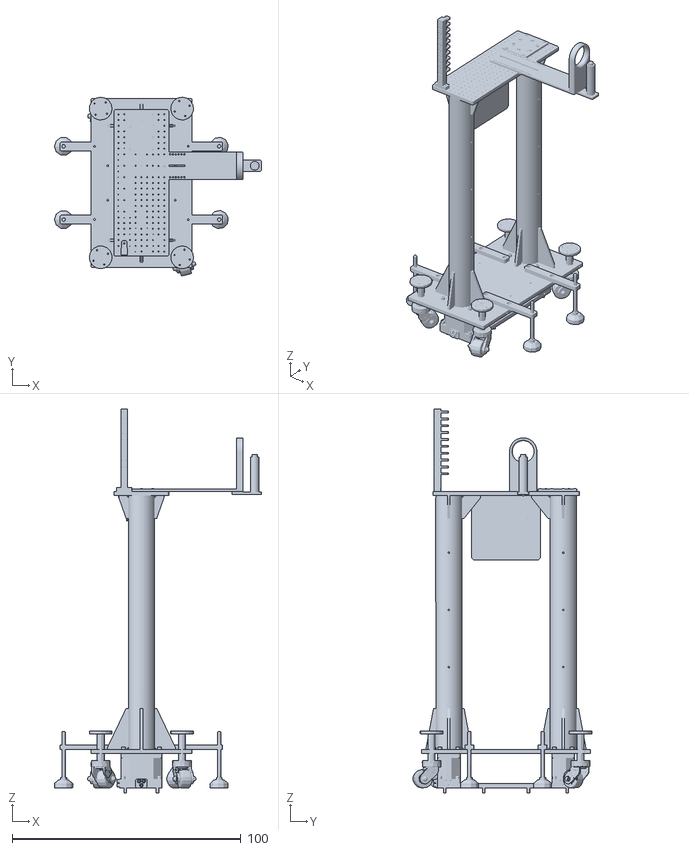
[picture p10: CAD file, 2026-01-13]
resources/stage.stl
90.5 x 78.1 x 167.8

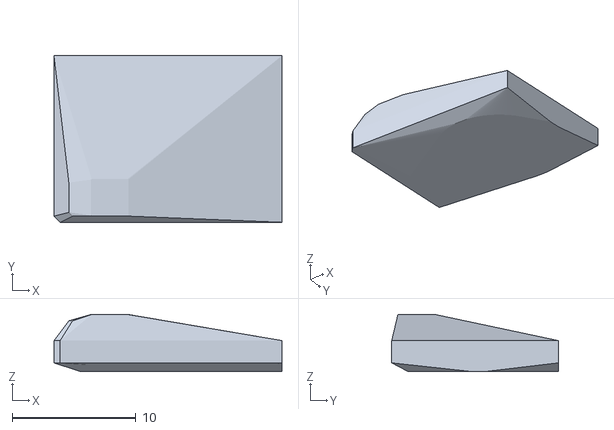
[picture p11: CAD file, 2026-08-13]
resources/stage_parts/stage_part10.stl
18.4 x 13.5 x 4.61

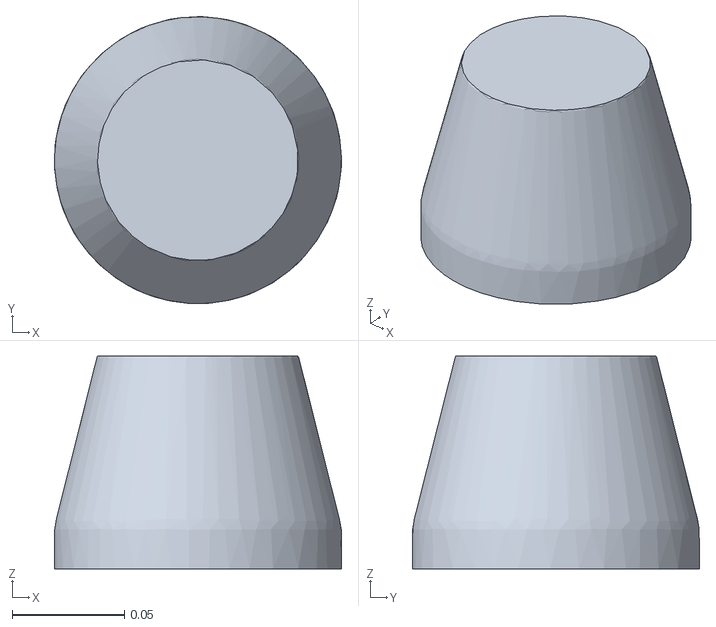
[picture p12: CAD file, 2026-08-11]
model/meshes/ur_description/meshes/ur3e/collision/base.stl
0.128 x 0.128 x 0.095

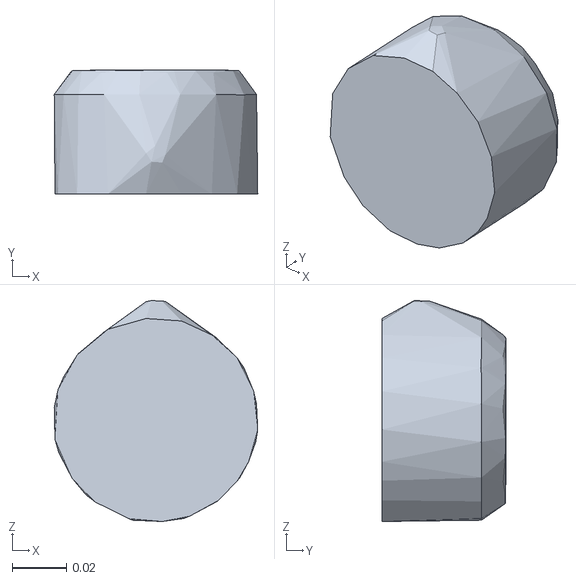
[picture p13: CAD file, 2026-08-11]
model/meshes/ur_description/meshes/ur5e/collision/wrist3.stl
0.0751 x 0.0458 x 0.0816

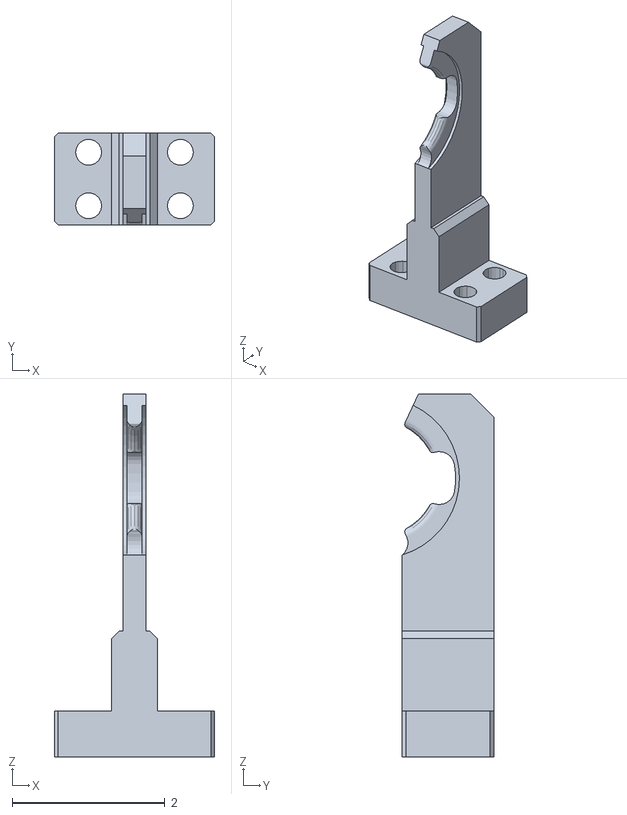
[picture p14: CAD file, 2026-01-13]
resources/gripper.stl
2.10 x 1.20 x 4.75

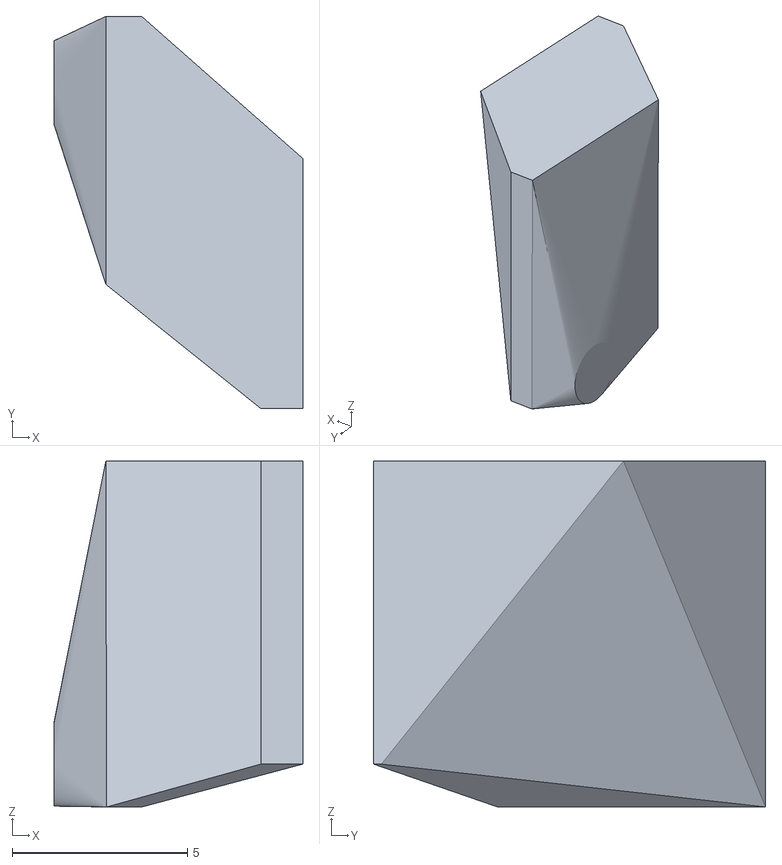
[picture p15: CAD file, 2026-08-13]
resources/stage_parts/stage_part34.stl
7.10 x 11.2 x 9.87

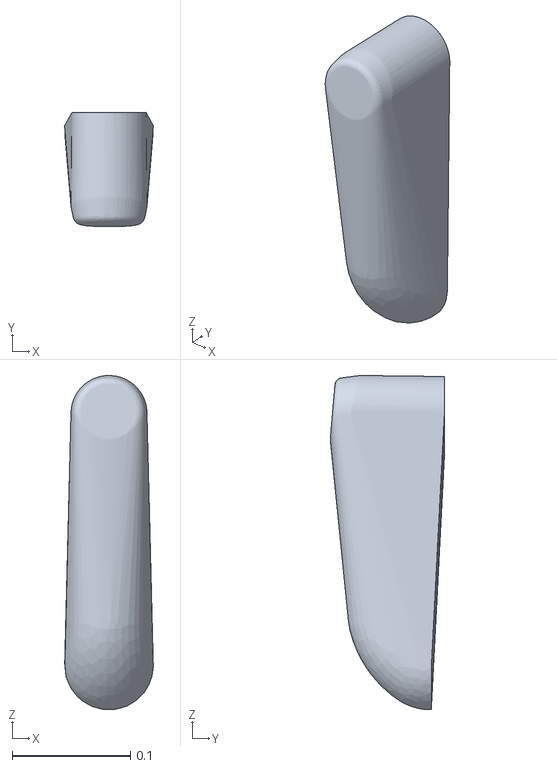
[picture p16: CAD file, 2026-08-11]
model/meshes/ur_description/meshes/ur3e/collision/forearm.stl
0.0751 x 0.0969 x 0.283

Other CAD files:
model/meshes/ur_description/meshes/ur5e/collision/base.stl
resources/stage_parts/stage_part04.stl
model/meshes/ur_description/meshes/ur3e/collision/shoulder.stl
model/meshes/ur_description/meshes/ur5e/collision/forearm.stl
model/meshes/ur_description/meshes/ur3e/collision/wrist2.stl
model/meshes/ur_description/meshes/ur3e/collision/wrist3.stl
model/meshes/ur_description/meshes/ur5e/collision/shoulder.stl
model/meshes/ur_description/meshes/ur5e/collision/wrist1.stl
resources/stage_parts/stage_part00.stl
resources/stage_parts/stage_part01.stl
resources/stage_parts/stage_part02.stl
resources/stage_parts/stage_part03.stl
resources/stage_parts/stage_part05.stl
resources/stage_parts/stage_part06.stl
resources/stage_parts/stage_part07.stl
resources/stage_parts/stage_part08.stl
resources/stage_parts/stage_part09.stl
resources/stage_parts/stage_part11.stl
resources/stage_parts/stage_part12.stl
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

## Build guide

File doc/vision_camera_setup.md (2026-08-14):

# 외부 고정 카메라 1대 + AprilTag — 성능/안정성 향상 가이드

전제: **외부 고정 카메라 1대**, **AprilTag(tag36h11)**.
전략 문서는 `doc/vision_inspection_plan.md`, 이 문서는 **실무 설정과 튜닝**만 다룬다.

읽는 순서: §1 → §2 를 먼저 하고, 나머지는 필요할 때 찾아보면 된다.
**§1과 §2만 제대로 해도 나머지 전부를 합친 것보다 효과가 크다.**

---

## 1. 가장 중요한 것: 카메라를 어디에 놓느냐

### 1.1 원칙 한 줄

> **재고 싶은 방향과 카메라가 보는 방향(광축)이 서로 수직이 되게 놓는다.**

카메라 1대는 **거리(깊이)를 잘 못 잰다.** 반대로 **이미지 평면 안의 위치는 아주 잘 잰다.**
차이가 크다 — 같은 카메라로 같은 물체를 봐도, 어느 축이냐에 따라 정밀도가 **10배 이상**
차이 난다.

```
카메라 ─────────▶  광축 방향 (Z)        ← 부정확  (거리, 깊이)
                   이미지 평면 (X, Y)   ← 정확    (좌우, 위아래)
```

### 1.2 이 셋업에 적용하면 → **정면 계열, 실제로는 30° 비스듬** (§1.2.3)

**⚠ Rev 3 정정**: 초판은 "퍽이 수평으로 꽂힌다"는 잘못된 가정으로 측면 뷰를 권했다.
코드 확인 결과 **수직 안착**이다:

```
above → on_position :  TCP local Y로 5 mm    ← 퍽을 포크에 내려놓음 (수직)
retreat             :  TCP local Z로 50 mm   ← 툴 축 방향 후퇴
slot pitch          :  TCP local Y로 30 mm × (N−1)   (holder_offset)
```
(`epics_triggered_sequence.cpp:1141-1144` — 오프셋은 **TCP 로컬 프레임** 기준.
`above_y_offset=-0.005`, `retreat_z_offset=-0.05`, `holder_offset=0.03`)

즉 "제대로 꽂혔나" = **퍽이 5 mm 제대로 내려앉았나** = **Y(수직)** 측정이다.
그리고 슬롯별 보정이 필요한 축은 **X(측방)** 와 **Z(깊이)** 다 (§1.2.1).

| 카메라 뷰 | 안착 Y (5 mm) | 측방 X (최대 3 mm) | 깊이 Z (최대 0.45 mm) |
|---|---|---|---|
| **정면 (권장)** | ✅ | ✅ | ❌ |
| 측면 | ✅ | ❌ | ✅ |
| 위 | ❌ | ✅ | ✅ |

→ **정면 뷰.** 안착(Y)과 가장 큰 보정축(X)을 동시에 잡는다. 포기하는 Z는 가장 작고
(0.45 mm), 지그 6-DoF 자세 피팅으로 대부분 흡수된다 (§1.2.1).

**정면 뷰 하나로 얻는 것:**
- 슬롯 10개 점유 (실루엣 있냐 없냐)
- 안착 높이 Δz (실루엣의 상하 위치) ← 판정의 핵심
- 기울기 (실루엣의 각도)
- 측방 오프셋 X (실루엣의 좌우 위치)

네 가지 전부 이미지 평면 안의 측정이라 정확하다.

### 1.2.1 기존 슬롯별 오프셋 18개의 정체 — 개체차가 아니라 기울기

`taught_waypoints.yaml` 의 손튜닝 값 (홀더 2–10, 피치 30 mm → 총 270 mm 구간):

```
홀더:   2      3      4      5      6     7     8     9    10
x:     0.3    0.5    1.5    1.5    3.0   3.0   3.0   3.0   3.0   mm
z:     0      0      0      0.2    0.25  0.3   0.35  0.4   0.45  mm
y:     보정 없음  ← 슬롯 피치 자체는 정확하다는 뜻
```

- **z**: 홀더 5부터 슬롯당 정확히 +0.05 mm. 270 mm에 0.45 mm → **0.095° 기울기**
- **x**: 270 mm에 3 mm → **0.64° 기울기**. 계단 모양(`0.3,0.5,1.5,1.5,3.0×5`)은 물리
  현상이 아니라 **손튜닝의 양자화**로 보인다

→ **10개 슬롯이 제각각 틀어진 게 아니라, 판 전체가 두 방향으로 기울어 있다.**
카메라로 랙의 6-DoF 자세를 재면 이 기울기는 **자세 파라미터가 통째로 흡수**한다.
슬롯마다 따로 재지 않아도 18개가 자세 하나로 대체된다.

**이행 시 주의 — 손튜닝값을 바로 지우지 말 것.** 그 값들은 실제 작동 결과로 수렴한
것이라 랙 기울기 + 로봇 절대 오차 + 그리퍼 편차가 **섞여** 있다. 카메라로 랙만 재면
그중 랙 성분만 본다. 순서:

```
1. 카메라 6-DoF 자세로 오프셋을 계산한다
2. 현재 손튜닝값과 비교만 한다 (아직 교체 안 함)
3. 차이가 작으면 → 기울기가 주원인 확인 → 교체
4. 차이가 크면  → 남는 차이가 로봇 절대 오차 → §1.2.2 상대 측정으로 간다
```

### 1.2.2 가장 강한 방법: 상대 측정 (look-then-move)

같은 프레임에서 **퍽과 목표 슬롯을 동시에** 보고, 둘 사이 어긋남을 직접 잰 뒤 그만큼
보정해서 하강한다. `vision_inspection_plan.md` §4.3의 Stage 2가 이것이다.

**이 셋업이 특히 유리한 이유: 두 물체가 5 mm 거리에 있다.**
`above` 포즈에서 퍽은 목표 슬롯 바로 위 5 mm다. 화면에서 거의 붙어 있는 두 물체를
재는 것이므로 — 같은 렌즈 영역(왜곡 상쇄), 같은 거리(배율 상쇄), 절대 좌표 미사용
(캘리브레이션·로봇 절대 오차 상쇄). **원인을 구분할 필요가 없다.** 랙 기울기든, 슬롯
가공 편차든, 로봇 절대 오차든 전부 "둘 사이 어긋남"에 이미 들어 있다.
FT를 차분으로 쓰는 것(§2.2 of plan)과 같은 원리다.

**연속 비주얼 서보잉이 아니라 look-then-move로 한다.**

```
[하지 말 것] 연속 VS: 움직이며 실시간 추종
  → MoveIt Servo, 저지연, 안정성 튜닝, 모션 블러 대응 필요
  → 그런데 목표물(슬롯)은 움직이지 않는다. 얻을 게 없다.

[할 것] look-then-move
  above 포즈 정지 (어차피 웨이포인트)
    → 1프레임 (정지 상태, 다중 프레임 평균 가능)
    → 어긋남 계산 → 상대 이동 → 하강
```
정지 측정이므로 **더 쉽고 더 정확하다.**

**그리퍼가 아니라 퍽을 본다.**

| 무엇을 보나 | 잡히는 오차 |
|---|---|
| 그리퍼 ↔ 슬롯 | 로봇 위치 오차만 |
| **퍽 ↔ 슬롯** | 로봇 위치 오차 **+ 파지 편차** |

퍽을 비뚤게 잡았으면 그리퍼는 제자리인데 퍽이 어긋난다. 정렬 대상은 퍽이다.

**픽셀↔mm 환산은 그 자리에서 직접 잰다 — 캘리브레이션 불필요.**

```
로봇을 X로 +1 mm 조깅 → 퍽이 화면에서 몇 픽셀 이동하는지 측정
→ "1 mm = 12 픽셀"  (그 포즈에서의 환산 계수)
→ 어긋남 36 픽셀이면 3 mm 보정
```
포즈마다 1회 측정해 두면 된다. `T_base_cam` 도, 내부 파라미터도, 왜곡 보정도, 좌표
변환도 거치지 않는다. **오차가 낄 자리가 거의 없다.**

**사이클 타임**: 삽입 지점 4곳 × 약 0.5 s(촬영 0.1 + 계산 0.01 + 상대 이동 0.4)
≈ 2 s. 다만 이 포즈들은 검사 지점(C1/C3/C5/C7)과 같은 자리이므로 한 프레임이
"슬롯 비었나"와 "얼마나 어긋났나"를 동시에 답한다 → 실제 추가는 더 적다.

(측정 자세는 step 3/9/14/20의 above가 아니라 그 앞 standby — step 1/7/12/18 —
로 옮겨졌다. above에서는 대상이 화면 밖이다. `doc/vision_correction_plan.md`
§12.4 참조. 이동 0.4 s는 별도 이동이 아니라 above로 가는 이동에 흡수된다.)

**안전장치: 보정량 상한.** 계산된 보정이 한계(예: 5 mm)를 넘으면 보정하지 말고 **정지**.
슬롯을 잘못 짚었거나, 랙이 크게 움직였거나, 검출이 틀린 상황이다. 그대로 보정하면
엉뚱한 곳으로 간다.

### 1.2.3 ⚠ 로봇 팔 가림 — 순수 정면이 아니라 30° 비스듬

그리퍼는 **local Z 방향으로 접근**해서 −50 mm로 후퇴한다. 순수 정면 뷰는 광축이 바로 그
Z 방향이므로 **로봇 팔이 카메라를 향해 정면으로 들어와 슬롯을 가린다.**

```
        랙
        ║
        ║◄── 퍽 (그리퍼가 Z로 접근)
        ║         ↖
        ║           로봇 팔 진입 통로
        ║
     ↙ 30°
  카메라  ← 통로를 비켜난다
```

| | 순수 정면 | **30° 비스듬 (권장)** |
|---|---|---|
| X (측방, 최대 3 mm) | 100 % | **87 %** |
| Z (깊이, 최대 0.45 mm) | 0 % | **50 %** (덤) |
| 로봇 팔 가림 | **심각** | 회피 |

타협이 아니라 개선이다 — X를 13 % 잃고, 가림을 피하고, 못 잡던 Z를 절반 얻는다.

**정확한 각도는 현장에서 정한다. 쉬운 확인법**: 후보 위치에 휴대폰을 두고 사이클을
한 번 돌려서 무엇이 가려지는지 본다. 카메라를 사기 전에 할 수 있다.

### 1.3 가림(occlusion)을 미리 설계한다

카메라가 1대뿐이라 **로봇 팔이 앞을 가리면 아무것도 못 본다.**

- 로봇이 랙에 접근하는 방향과 **다른 쪽**에 카메라를 놓는다.
- 촬영은 팔이 비켜난 포즈(`standby`, `retreat`)에서만 한다. 어차피 검사 시점이 그렇다.
- **가려졌을 때 추측하지 않는다.** 태그가 안 보이거나 ROI가 팔에 덮이면 → `UNKNOWN` →
  정지. "아마 비어 있겠지"가 사고를 만든다.

### 1.4 마운트 강성 — 의외로 가장 흔한 실패 원인

카메라가 **0.1°만 기울어도** 1 m 거리에서 **1.7 mm** 어긋난다. 요구 정밀도가 0.7 mm인데.

- 얇고 긴 폴에 매달지 말 것. **짧고 굵게.**
- **로봇과 같은 테이블(브레드보드)에 직접 고정.** 벽이나 천장은 안 된다 —
  온도와 건물 진동으로 로봇과 따로 움직인다.
- 삼각대 금지. 조인트가 미세하게 흐른다.
- 나사는 풀림방지 처리.

---

## 2. 두 번째로 중요한 것: 백라이트 (역광) 실루엣

### 2.1 왜 이게 그렇게 좋은가

지금 가장 큰 기술 리스크가 **알루미늄 반사**다. 앞에서 빛을 비추면 금속이 번쩍여서
에지가 사라지고 depth가 뚫린다. 조명을 아무리 잘 잡아도 완전히는 못 없앤다.

**뒤에서 비추면 이 문제가 통째로 사라진다.**

```
   확산 백라이트 패널        퍽/랙            카메라
   ░░░░░░░░░░░░░  ──빛──▶  ██████  ─────▶   ●
   (균일한 흰 면)          (검은 실루엣)

   → 물체는 완전한 검은색, 배경은 완전한 흰색
   → 에지가 극단적으로 선명. 서브픽셀 측정 가능
   → 표면 반사·색·오염·주변 조명 변화 전부 무관
```

산업용 치수 측정은 거의 항상 이 방식을 쓴다. 이유가 있다.

### 2.2 얻는 것

| | 앞에서 조명 | 백라이트 실루엣 |
|---|---|---|
| 금속 반사 | 심각한 문제 | **무관** |
| 주변 조명 변화(형광등, 낮/밤) | 영향 받음 | **무관** |
| 배경 잡음 | 영향 받음 | **무관** |
| 에지 선명도 | 보통 | **극대** |
| 필요한 알고리듬 | 복잡 | **임계값 하나** |
| ML 필요성 | 있을 수도 | **없음** |

`UNKNOWN` 발생률(= ML 투입 여부의 판단 기준)을 가장 확실하게 낮추는 방법이다.

### 2.3 실무 주의

- **확산(diffuse) 패널**을 쓴다. LED 점광원을 그냥 두면 안 된다. 얇은 LED 패널 + 유산지/
  아크릴 확산판.
- **⚠ 퍽과 그리퍼가 한 덩어리로 붙어 보일 수 있다.** 상대 측정(§1.2.2)은 퍽의 윤곽을
  그리퍼와 분리해서 봐야 한다. 퍽 원반이 손가락 바깥으로 충분히 튀어나오는지 실물 확인
  필요. 안 되면 (a) 백라이트를 슬롯 영역에만 국한하고 퍽 영역은 전면 조명, 또는
  (b) 노출을 달리한 2프레임을 번갈아 찍는다.
- 랙 뒤 공간이 필요하다. 사진상 랙 뒤는 파티션이라 **얇은 패널이면 가능해 보이지만
  실측 확인 필요** (§6-1).
- 밝기는 **고정**. 조광 가능한 제품이면 다이얼을 고정하고 표시해 둔다.
- 카메라 노출을 백라이트에 맞춰 고정하면 주변 조명은 아예 무시된다.
- **태그는 백라이트로 못 읽는다** (검은 실루엣이 되어버림). 태그는 카메라 쪽에서 조명받는
  면에 붙이고, 실루엣 측정 영역과 분리한다. 필요하면 태그 검출용 프레임과 실루엣 측정용
  프레임을 **노출 다르게 번갈아 찍는다** (같은 카메라로 2장, 0.1초).

---

## 3. AprilTag를 잘 쓰는 법

### 3.1 왜 AprilTag가 ArUco보다 나은가 (좋은 선택입니다)

- **오검출(false positive)이 훨씬 적다.** tag36h11은 해밍 거리가 커서 잘못 읽을 확률이
  극히 낮다. 지그 위치를 잘못 커밋하면 충돌이므로, 이 특성이 안전에 직결된다.
- 비스듬한 각도, 부분 가림, 낮은 조도에서 검출률이 높다.
- 검출 속도는 ArUco보다 느리지만, 카메라 1대 / 수 Hz면 전혀 문제 안 된다.

**단, 자세(회전) 정밀도 문제는 AprilTag도 똑같다.** 평면 태그 하나의 PnP는 원리적으로
면외 회전이 부정확하고, 자세가 뒤집혀 보이는 경우(ambiguity)가 있다. 태그를 바꾼다고
해결되지 않는다 — §3.3의 배치로 해결한다.

### 3.2 즉시 바꾸면 되는 설정 3개 (공짜)

**① `quad_decimate = 1.0`**
기본값이 보통 2.0인데, 이건 이미지를 절반으로 줄여서 검출한다. 속도는 빨라지지만
**정밀도가 그만큼 날아간다.** 정밀 측정에는 반드시 1.0.
→ 가장 흔하고 가장 아까운 정밀도 손실.

**② 노출 고정 (auto-exposure OFF)**
자동 노출은 프레임마다 밝기가 바뀌고, 밝기가 바뀌면 에지 검출 위치가 미세하게 흔들린다.
→ 노출·게인·화이트밸런스 **전부 수동 고정.** 오토포커스 렌즈면 초점도 고정.
→ 이거 하나로 재현성이 눈에 띄게 좋아진다.

**③ `refine_edges = true`**
서브픽셀 에지 정제. 켜 둔다. 비용 거의 없다.

### 3.3 태그 배치 3개 원칙

**① 크게** — 이미지에서 태그 한 변이 **최소 100 픽셀** 이상 되게. 작으면 정밀도가 급격히
나빠진다. 작은 태그 여러 개보다 큰 태그 하나가 낫다.

**② 멀리 떨어뜨려서** — 자세(회전) 정확도는 태그 사이 거리에 반비례해서 좋아진다.

```
   [나쁨] 모아 붙임              [좋음] 멀리 배치

   ┌────────┐                  ┌────────┐
   │ ▣▣▣    │                  │ ▣      │  ← 위
   │        │                  │        │
   │        │                  │        │
   │        │                  │   ▣   ▣│  ← 아래 양쪽
   └────────┘                  └────────┘

   baseline 짧음 → 각도 오차 큼    baseline 김 → 각도 오차 작음
```
랙 위·아래 끝에 하나씩, 그리고 하나 더. **세 점이 일직선이 되지 않게.**

**③ 측정 대상과 같은 평면에** — 태그 면과 슬롯 기준면이 다르면 그 사이 변환을 따로
알아야 하고, 그게 새로운 오차원이 된다. 지그의 **가공된 기준면**에 붙인다.

### 3.4 여러 태그를 "묶어서" 푼다 (tag bundle)

태그마다 포즈를 따로 구해서 평균내면 안 된다. **모든 태그의 코너를 한 번에 PnP에 넣는다.**
"이 태그들은 서로 이만큼 떨어진 하나의 강체"라는 정보를 쓰는 것이고, 이게 §3.3-②의
baseline 효과를 실제로 얻는 방법이다.

`apriltag_ros`에 **tag bundle** 기능이 이걸 위해 있다. standalone tag 대신 bundle로 설정.
번들 정의에는 태그 간 상대 위치를 mm 단위로 정확히 적어야 하므로, **태그를 판에 붙일 때
치구를 쓰거나 판 자체에 각인**하는 게 좋다.

### 3.5 태그 크기 — 여기서 틀리면 모든 거리가 비례해서 틀린다

- 설정에 넣는 크기는 **의도한 값이 아니라 캘리퍼로 실측한 값.**
  프린터는 100%로 설정해도 1~2% 어긋난다. 1% 오차 = 1 m 거리에서 10 mm 오차.
- **크기의 정의를 문서에서 확인할 것.** 도구마다 "검은 테두리 바깥 변"인지 "데이터
  영역 변"인지 다르다. 여기서 헷갈리면 수 % 오차가 조용히 들어간다.
- **종이 금지.** 습기·마모로 서서히 변형되는데, 정밀도가 조용히 나빠져서 알아채기 어렵다.
  → **알루미늄 각인 / 아노다이징 마킹** 권장. 재설치가 잦으면 더욱.

### 3.6 흔한 검출 실패

- **흰 여백 부족** — AprilTag는 검은 테두리 바깥에 최소 1비트 폭의 흰 여백이 필요하다.
  딱 맞춰 자르면 검출이 안 된다.
- **광택 표면** — 무광으로. 코팅된 알루미늄이 번쩍이면 태그가 안 읽힌다.
- **모션 블러** — 고정 카메라 + 정지 촬영이면 무관. 노출 시간만 너무 길지 않게.
- **태그가 너무 작음** — §3.3-① 참조.

---

## 4. 카메라와 렌즈

### 4.1 필요한 분해능을 먼저 계산한다 (간단함)

```
mm/픽셀 = 시야 크기(mm) ÷ 픽셀 수
측정 분해능 ≈ (mm/픽셀) ÷ 5     ← 좋은 에지에서 서브픽셀 1/5 픽셀 가정
```

예: 랙 높이 400 mm를 세로 1200 픽셀로 본다면

```
400 ÷ 1200 = 0.33 mm/픽셀
0.33 ÷ 5   = 0.07 mm  → 판정 기준 0.7 mm 대비 10배 여유. 충분.
```

640×480 웹캠이면: `400 ÷ 480 = 0.83 mm/px` → `0.17 mm`. 여유 4배 — 아슬아슬하다.

**목표: 판정 임계값(dz_max) 대비 분해능 여유 5배 이상.**
시야를 랙만으로 좁힐수록 좋아진다. 필요 없는 배경을 화면에 담지 않는다.

### 4.2 고를 때

| 항목 | 권장 | 이유 |
|---|---|---|
| 셔터 | **글로벌 셔터** | 롤링 셔터는 진동에 왜곡 |
| 해상도 | **1920×1200 (2.3 MP) 이상** | §4.1 계산 결과 충족 |
| 센서 | **모노크롬** (컬러보다 유리) | 베이어 보간이 없어 에지가 선명, 감도 2배. 치수 측정은 모노가 정석 |
| 렌즈 | **고정 초점거리, 저왜곡** | 바리포컬/줌 금지 — 재현성이 없다 |
| 인터페이스 | USB3 또는 GigE | |

컬러가 꼭 필요한 이유가 없으면 모노를 쓴다. 실루엣 측정에는 색이 아무 의미 없다.

### 4.3 내부 파라미터 캘리브레이션은 제대로

태그 포즈 정확도의 **상한**을 여기서 결정한다. 대충 하면 뒤에서 뭘 해도 안 올라간다.

- ChArUco 보드로 **20~30장**. (내부 캘리브레이션에는 ChArUco가 여전히 좋다 —
  지그 로컬라이제이션에 AprilTag를 쓰는 것과 별개 얘기다.)
- **화면 구석까지 골고루.** 가운데만 찍으면 왜곡 계수가 안 나온다.
- 보드를 기울여서도 찍는다.
- 왜곡 계수까지 추정한다.
- 재투영 오차(reprojection error) **0.3 픽셀 이하** 목표. 넘으면 다시.

### 4.4 켜고 나서 20분 기다린다

센서가 데워지면서 초점과 기하가 미세하게 변한다. **전원 켜고 10~20분 후에**
캘리브레이션하고, 운영 중에도 아침 첫 사이클 전에 예열한다.

---

## 5. 안정성 — 시간이 지나도 안 틀어지게

성능은 처음 한 번 잘 맞추면 되지만, 안정성은 **틀어졌다는 걸 스스로 알아채는 구조**를
만드는 문제다.

### 5.0 헷갈리기 쉬움: "캘리브레이션(1회)"과 "측정(매번)"은 다른 것

카메라가 하는 일은 두 가지이고, 주기가 다르다.

```
[매번]  측정:        T_cam_rack    "랙은 카메라에서 왼쪽 30cm, 앞 50cm"
                                    ↑ 카메라 말이라 로봇이 못 알아들음
[1회]   캘리브레이션: T_base_cam    "카메라는 로봇에서 이 위치, 이 방향"
                                    ↑ 번역 규칙
[결과]              T_base_rack = T_base_cam · T_cam_rack
                                    ↑ 로봇이 실제로 갈 수 있는 좌표
```

자에 비유하면 **눈금을 새기는 건 한 번**(캘리브레이션), **그 자로 재는 건 잴 때마다**
(측정). 눈금 없는 자로는 매번 재도 숫자가 안 나온다.

| 무엇 | 주기 | 이유 |
|---|---|---|
| `T_base_cam` (번역 규칙) | **평생 1회** | 카메라와 로봇이 같은 브레드보드에 고정 → 안 변함 |
| `T_cam_rack` (지그 위치) | **재설치마다** (최소), 권장은 **매 사이클** | 지그가 움직이니까 |
| 슬롯별 미세 보정 | **매 사이클** | 잔여 오차 흡수 (`vision_inspection_plan.md` §4.3) |

**매 사이클 갱신을 권한다.** 어차피 태그가 화면에 있으니 비용이 거의 없고, "누가 랙을
툭 쳤다"를 즉시 잡아낸다. 단 안전장치가 필요하다:

- **작은 변화**(노이즈 수준) → 평활화해서 반영
- **큰 변화**(예: 5 mm 이상) → 반영하지 말고 **정지 + 운영자 확인**.
  태그 오검출로 잘못된 위치를 그대로 믿으면 다음 동작이 충돌이다.

### 5.0.1 캘리브레이션은 "로봇 위치를 알기 위해서"가 아니다

자주 하는 오해다. **로봇은 자기 팔이 어디 있는지 이미 안다** — 관절 엔코더 + 순기구학
(TF `base_link → tool0`). 반복정밀도 ±0.03 mm로, 카메라로 재는 것보다 훨씬 정확하다.

카메라가 필요한 이유는 **로봇이 못 느끼는 것**(랙, 측정 홀더 — 엔코더가 없다)의 위치를
알기 위해서다. 캘리브레이션은 그 정보를 **카메라 좌표 → 로봇 좌표로 옮기는 번역기**다.

캘리브레이션 절차(그리퍼에 태그 붙이고 로봇을 움직이며 관측)가 로봇을 측정하는 것처럼
보이지만 반대다 — **로봇이 자기 위치를 정확히 알기 때문에 그것을 기준자로 삼아** 카메라를
로봇 좌표계에 정렬시키는 것이다.

### 5.0.2 카메라↔로봇 캘리브레이션은 1회면 끝난다

**eye-in-hand(손목 카메라용)는 안 해도 된다** — 손목에 카메라가 없으니까.
**하지만 `T_base_cam`(카메라↔로봇 베이스)은 반드시 필요하다.** 카메라가 "랙이 여기 있다"고
말해도, 그게 로봇 좌표로 어디인지 모르면 로봇이 못 간다.

```
T_base_rack = T_base_cam · T_cam_rack
              ▲
              └── 이게 없으면 아무것도 안 됨
```

이건 eye-in-hand가 아니라 **eye-to-hand** 캘리브레이션이다. 그리고 **카메라를 로봇과 같은
브레드보드에 고정하면(§1.4) 평생 1회로 끝난다:**

| 상황 | 재캘리브레이션 |
|---|---|
| 랙만 재설치 | **불필요** |
| 셀 전체 이사 (로봇+카메라 함께) | **불필요** |
| 카메라·렌즈·초점을 건드림 | 필요 |
| 로봇을 브레드보드에서 분리 | 필요 |

§1.4에서 마운트를 테이블 직결로 권한 이유가 진동 때문만이 아니다.
**캘리브레이션 수명** 때문이다.

절차는 간단하다 — 태그를 그리퍼에 붙이고, 로봇을 10~20 자세로 움직이며 관측하고,
`cv2.calibrateHandEye`. 로봇 기구학이 자 역할을 하므로 별도 측정 도구가 필요 없다.
기존 `hand_eye_calibration_node.py` 의 `invert_gripper2base: true` 가 이 변환을 이미
지원한다. 상세는 `vision_inspection_plan.md` §4.1 (M3).

**놓치기 쉬운 두 가지:**
- **자세의 회전을 충분히 다양하게.** 위치만 옮기고 방향을 안 바꾸면 해가 불안정해진다.
- **내부 파라미터를 먼저 실측할 것.** 기존 노드는 D405 값이 하드코딩돼 있고
  `dist_coeffs = zeros(5)` 다. 새 카메라에는 틀리다 (§4.3).

### 5.1 자기 검증 태그 — 가장 쉽고 가장 효과적

**여분 태그 하나를 로봇 베이스에 영구 부착한다.**
매 측정마다 그 태그까지의 거리·각도를 계산해서 저장된 기준값과 비교한다.

브레드보드 임의 위치가 아니라 **로봇 베이스**에 붙이는 이유: §5.0의 `T_base_cam` 이
1회 캘리브레이션으로 고정되므로, 그 관계가 유지되는지를 직접 감시해야 한다.
지키고 싶은 관계를 정확히 겨냥하는 것이다.

```
매일 아침 자동 체크:
  기준 태그 포즈 측정 → 저장값과 비교
    차이 < 0.3 mm  → 정상
    차이 ≥ 0.3 mm  → "카메라가 움직였습니다" 경고 → 재캘리브레이션
```

카메라 마운트가 밀렸는지, 나사가 풀렸는지, 온도로 흘렀는지를 **사람이 알아채기 전에**
잡아낸다. 태그 하나 붙이고 비교 코드 몇 줄이면 끝난다.

### 5.2 상시 기록할 지표 4개

이 값들을 PV로 내보내고 추세를 본다. **값 자체보다 추세가 중요하다.**

| 지표 | 나빠지면 의미하는 것 |
|---|---|
| 태그 포즈의 프레임 간 표준편차 | 진동, 조명 흔들림, 노출 문제 |
| 태그 검출 실패율 | 태그 오염/손상, 조명 변화, 가림 |
| 기준 태그 오차 (§5.1) | 카메라 마운트 이동 |
| 정상 안착 Δz 분포의 평균 | 기구 마모, 지그 변형 |

마지막 항목이 특히 유용하다 — **고장 나기 전에** 기구 문제를 알려준다.

### 5.3 여러 프레임 평균

재설치 캘리브레이션은 어차피 로봇이 멈춰 있을 때 한다. **10~30 프레임 평균**을 쓴다.
랜덤 노이즈가 √N배로 줄어든다 (25장이면 1/5). 시간은 1초도 안 걸리고 공짜다.

단, **평균 전에 이상치를 버린다.** 태그가 한 프레임에서 잘못 뒤집혀 검출되면 평균이
오염된다. 중앙값(median) 또는 이상치 제거 후 평균.

### 5.4 정기 점검 항목

| 주기 | 항목 |
|---|---|
| 매일 (자동) | 기준 태그 검증 (§5.1) |
| 재설치 시 | 지그 로컬라이제이션 3회 반복 → σ 확인 → 운영자 승인 |
| 월 1회 | 태그 오염/손상 육안 점검, 렌즈 청소, 마운트 나사 확인 |
| 6개월 | 내부 파라미터 재캘리브레이션 |

---

## 6. 남는 문제와 대안

### 6.1 카메라 1대로 안착 판정이 되는가

**정면 뷰 + 백라이트(§1.2, §2)가 되면 — 된다.** 안착 높이(Y)와 기울기, 측방 오프셋(X)이
전부 이미지 평면 안의 측정이 되므로 오히려 유리하다.

**정면 배치나 백라이트가 물리적으로 불가능하면 — 어렵다.** 그 경우 대안:

1. **손목 D405를 병용한다** (권장 대안). 이미 있고, hand-eye 캘리브레이션 인프라도 있다.
   역할 분담이 깔끔하다:
   - **외부 고정 카메라**: 지그 로컬라이제이션(AprilTag), 10슬롯 재고, 점유 판정
   - **손목 D405**: 안착 근접 검사 (Δz, 기울기)

   "외부 1대"라는 결정과 충돌하지 않는다 — 새로 사는 카메라가 1대일 뿐, 이미 있는
   D405를 놀리는 게 오히려 손해다.

2. **접촉식 확인** — 안착 후 그리퍼를 살짝 내려 퍽 상단에 닿는 높이를 FT로 잰다.
   비전 없이 Δz를 직접 측정하는 방법. 사이클 타임이 늘고 퍽에 접촉하지만 확실하다.

3. **측정 홀더에 근접 센서** — 광전/정전용량 센서 하나로 "완전히 안착됨"을 판정.
   측정 홀더는 1개뿐이라 비용이 작다. 랙 10슬롯은 비용이 커서 안 맞는다.

### 6.2 카메라 1대 배치로 랙과 측정 홀더를 동시에 볼 수 있는가

사진상 랙과 측정 홀더가 떨어져 있다. 한 화면에 둘 다 담으면 **시야가 넓어져서 mm/픽셀이
나빠진다** (§4.1). 선택지:

- **랙 위주로 배치**하고 측정 홀더는 손목 카메라 담당 (6.1-1과 같은 결론)
- 광각으로 둘 다 담되 분해능 여유를 §4.1로 계산해서 확인. 여유 5배 안 나오면 포기.

→ **§6-1의 실측 확인 후 결정.**

---

## 7. 우선순위 요약

효과가 큰 순서다. 위에서부터 하면 된다.

| 순위 | 항목 | 비용 | 효과 |
|---|---|---|---|
| 1 | **30° 비스듬 정면 배치** (측정축 ⊥ 광축 + 팔 가림 회피) — §1.2, §1.2.3 | 0 (배치만) | 절대적 |
| 1b | **상대 측정 (퍽↔슬롯, look-then-move)** — §1.2.2 | 저 | 절대적 |
| 2 | **백라이트 실루엣** — §2 | 저 (LED 패널) | 절대적 |
| 3 | **`quad_decimate=1.0` + 노출 고정** — §3.2 | 0 (설정) | 큼 |
| 4 | **태그 3개 이상 멀리 + tag bundle** — §3.3~3.4 | 저 | 큼 |
| 5 | **강성 마운트, 테이블 직결** — §1.4 | 저 | 큼 |
| 6 | **내부 캘리브레이션 제대로** — §4.3 | 시간 | 상한을 결정 |
| 7 | **자기 검증 태그** — §5.1 | 거의 0 | 안정성의 핵심 |
| 8 | 태그 알루미늄 각인 — §3.5 | 중 | 장기 안정성 |
| 9 | 다중 프레임 평균 — §5.3 | 0 | 중 |
| 10 | 모노크롬 글로벌셔터 카메라 — §4.2 | 중 | 중 |

**1~3번만 해도 대부분의 문제가 해결된다.** 4~7번까지 하면 재설치가 잦아도 안정적으로
돌아간다.

---

## 8. 확인 필요 (실측해야 결정되는 것)

1. **로봇 팔 가림 각도** — §1.2.3. 후보 위치에 휴대폰을 두고 사이클을 한 번 돌려
   무엇이 가려지는지 확인한다. **카메라 구매 전에 할 수 있다. 최우선.**
2. **랙 뒤에 백라이트 패널을 넣을 공간이 있는가** — 사진상 파티션까지의 거리.
3. **퍽 실루엣이 그리퍼와 분리되는가** — §2.3. 상대 측정(§1.2.2)의 전제 조건.
4. **`above` 포즈에서 퍽과 목표 슬롯이 한 프레임에 들어오는가** — 5 mm 간격이므로
   거의 확실하지만, 시야 범위와 함께 확인.
3. **랙과 측정 홀더를 한 화면에 담을 때의 시야 크기** — §4.1 계산 입력.
4. **로봇 팔이 랙을 가리는 포즈 범위** — 촬영 시점 결정 입력.
5. `apriltag_ros`의 ROS2 Humble 패키지 가용성과 tag bundle 설정 형식 — 로봇 PC에서 확인.
6. 태그 크기 정의(검은 테두리 바깥 변 vs 데이터 영역) — 쓰는 패키지 문서에서 확인.

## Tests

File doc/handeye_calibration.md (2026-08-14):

# Hand-eye 캘리브레이션 결과 — eye-in-hand D405

`doc/vision_correction_plan.md` §4(Phase 1)의 실행 기록. 계획서는 무엇을
왜 하는지를, 이 문서는 **실제로 나온 값과 그 값을 믿을 근거**를 담는다.

기준 산출물은 `T_ee_cam.yaml`(저장소 루트, `solve_joint.py`가 씀).
`T_ee_cam_axxb.yaml`은 `solve.py`의 교차검증용이며 **기준이 아니다**.

---

## 1. 결과

| 항목 | 값 | 1σ |
|---|-----|-----|
| `T_ee_cam` 병진 | (−5.56, −52.33, −51.90) mm | (0.43, 0.41, 0.49) mm |
| `T_ee_cam` 회전 | (−12.35, 4.84, 1.12)° | — |
| fx / fy | 396.99 / 395.80 px | fx 0.86 px |
| cx / cy | 325.75 / 254.64 px | — |
| 태그 한 변 | 98.585 mm | 0.098 mm |

- 표본 42뷰(회전 33 + 프레임 sweep 9), 336개 코너 좌표, 미지수 22
- 코너 잔차 0.887 px RMS, χ²/dof 4.5
- Leave-one-out 홀드아웃 0.872 px — 인샘플과 같으므로 과적합 없음
- 1σ는 √(χ²/dof)로 부풀린 값(관측 산포 반영). 액면 σ는 이보다 2.1배 낙관적

수집 원본: `handeye_samples/samples.yaml`.

## 2. 왜 결합 풀이인가

`cv2.calibrateCamera`는 뷰마다 태그 자세 6개를 자유 미지수로 둔다. 42뷰면
261 미지수 대 336 좌표, 순 75. 실제로 미결정으로 나왔다 — 캡처된 코너를
0.08 px 이내로 똑같이 설명하는 두 렌즈 모델이 fx에서 9%, 태그 위치에서
27 mm 어긋났다.

로봇은 그 뷰들 사이를 어떻게 움직였는지 이미 안다. FK를 고정하면 뷰별 자세
252개가 모든 뷰가 공유하는 두 자세(플랜지 위 카메라, 베이스 프레임의 태그)로
접히고, 같은 336개 숫자가 22개 미지수를 상대한다.

Depth는 평면의 **오프셋만** 쓴다. 그 오프셋은 depth-컬러 프레임 간 회전과
정렬 확인이 한정만 하고 특정하지 못한 수 픽셀 매핑(5 px 미만, 스테레오
베이스라인이라면 31 px) 양쪽에 불변이다. 평면의 법선은 둘 다에 불변이 아니다.
그리고 이건 여기서 유일하게 각도가 아닌 측정이다 — 영상만으로는 초점거리와
태그 실제 변 길이가 서로 상쇄되며 맞바꿔진다.

## 3. 태그 98.585 mm

`doc/apriltags/generate.py`가 그린 값은 100.0 mm(바깥 검은 사각형)다.
`detector.py`도 `TAG_SIZE_M = 0.100`을 쓴다. 실측은 98.585 mm, −1.42%다.

근거:

- 독립 캡처 3회에서 98.388 / 98.588 / 98.575 mm
- σ_depth를 0.2~5 mm로 흔들어도 98.537~98.587로 불변
- depth를 아예 꺼도(`--no-depth`) 98.575 mm — 이때 metric scale은 **로봇
  이동거리**에서 온다. 즉 서로 독립인 자 두 개(팔의 이동, depth 카메라)가
  같은 값을 가리킨다
- 코너 규약 확인: 측정/공칭 = 0.9859. 테두리 셀 중심(7/8 = 0.875)도
  데이터 영역(6/8 = 0.75)도 아니므로 코너는 바깥 검은 모서리에 있다

**원인은 미확정.** 두 후보가 똑같이 짧게 읽힌다:

1. 인쇄 축소 — fit-to-page가 보통 이 대(96~98%)
2. 시트 비평면 — 종이는 늘어나지 않으므로 가운데가 부풀면 코너 간 직선거리가
   인쇄 길이보다 짧아진다

2번이 실재한다는 것은 확인됐다. 24프레임 스택 후 태그 면의 최적합 평면 이탈이
**0.77~0.89 mm RMS**이고, 8×8 블록 평균에서 0.791 mm로 거의 안 줄어든다(순수
잡음이면 0.109 mm여야 한다) — 공간 상관된 실제 형상이다. 태그 무늬에 물린
스테레오 인공물도 아니다: 밝기 상관 −0.044, 검은/흰 영역 평면 이탈 차이
0.066 mm, 인쇄 경계 근처 잔차가 오히려 작다(0.701 vs 0.773 mm).

다만 **얼마나 기여하는지는 못 박았다.** 기울기로 환산한 현 단축률이 평활화
규모에 따라 0.15%(8 px)에서 1.17%(2 px)까지 움직이고 안정 구간이 없다. 필요한
값은 1.420%다. 절반은 확실히 설명하고, 전부일 수도 있다.

`generate.py` 자신이 *"Mount it flat. A bulge of 1 mm over 100 mm is already
0.6 deg of pose error"* 라고 경고한다. 0.8 mm RMS는 그 한계선이다.

**가리는 법**, 결정력 순:

1. 시트를 평판(유리·알루미늄)에 다시 붙이고 재수집. 태그 크기가 100 쪽으로
   올라가면 마운팅, 98.6에 머물면 인쇄. 어느 쪽이든 이건 고쳐야 할 상태다
2. 캘리퍼로 1페이지의 100 mm 자눈금. 종이를 펴서 재므로 인쇄 배율만 나온다.
   태그 검은 모서리보다 눈금이 낫다 — 토너 번짐 때문에 캘리퍼 턱 물리는
   위치가 애매해진다

균일 축소가 맞다면 2페이지 홀더 태그 10 mm도 실제 9.86 mm다.

## 4. 잔차 0.887 px의 정체 — 렌즈가 아니라 팔

χ²/dof 4.5는 모델이 관측 잡음 수준까지 안 맞는다는 뜻이다. 원인을 갈랐다.

- **렌즈 아님.** rational 모델(k4~k6)을 넣으면 k1=−11.9/k4=−11.9,
  k2=+50.2/k5=+50.3으로 분자≈분모 폭주하고 얻는 건 0.887→0.874 px뿐,
  corners-only fx의 σ는 16 px로 터진다. 자유도만 늘고 정보는 없다
- **검출기 아님.** 잔차를 분해하면 81%가 네 코너 공통 평행이동이고,
  shift+scale+rotation을 빼면 0.274 px 남는다 — `SIGMA_PX` 가정치 0.30과 일치
- **팔이다.** 공통 평행이동 0.797 px는 작업거리 294 mm에서 0.59 mm의 자세
  오차다. 자세를 2° 이내로 고정하고 보면 TCP 40~70 mm 떨어진 뷰끼리 0.38 mm,
  110 mm 이상이면 1.01 mm로 어긋나며 상관 +0.548 — 구성에 대해 매끄러운 장,
  즉 UR3e의 절대 정확도다(반복도 ±0.03 mm와 다른 값)

카메라 쪽에서 더 짜낼 것은 없다. 더 줄이려면 팔의 기구학 보정이 필요하고,
그건 별개의 작업이다.

## 5. 실사용 오차 예산

시퀀서의 비전 보정은 `DX/DY/DZ` TCP-로컬 **순수 병진**이다. 카메라 프레임의
보정 벡터를 TCP로 옮길 때 `R_ee_cam`만 쓰이고 `t_ee_cam`은 소거된다(회전이
섞일 때만 |δt|·θ로 되살아난다). 5 mm 보정 기준:

| 항 | 값 | 5 mm 보정 기여 |
|----|-----|---|
| `R_ee_cam` 캡처 간 스프레드 | 0.79° | 0.07 mm |
| 스케일(fx + 태그 크기) | 0.43% | 0.02 mm |
| 측정당 검출 잡음 | 0.27 px @ 294 mm | 0.20 mm |

**캘리브레이션은 제한 요소가 아니다. 측정 잡음이 지배한다.**

## 6. 재현성

독립 캡처 3회, corners-only 기준:

```
run10 rotation only   t=( -5.22,-51.81,-51.92)  fx 395.37  tag 98.388  33뷰
run11 + frame sweep   t=( -5.67,-51.58,-49.45)  fx 393.67  tag 98.588  42뷰
run12 (same poses)    t=( -5.70,-51.62,-49.52)  fx 393.90  tag 98.575  42뷰
run12 + depth         t=( -5.56,-52.33,-51.90)  fx 396.99  tag 98.585  42뷰
```

- run11 vs run12는 0.02/0.04/0.06 mm 일치 — 같은 포즈를 9분 간격으로 다시 찍은
  별개 캡처이므로 랜덤 성분은 사실상 없다
- 유일하게 벌어지는 축은 t_z 2.4 mm이고, 원인은 캡처 드리프트가 아니라 sweep
  뷰다: depth 없이 sweep을 넣으면 −51.9 → −49.5로 끌리고, depth를 넣으면
  −51.90으로 돌아온다. 회전 뷰만의 답(−51.92)과 전체+depth(−51.90)가 0.02 mm로
  만난다
- 태그는 캡처 내내 고정이었고 세 풀이가 각자 독립으로 복원한 `base_T_tag`가
  0.819 mm / 0.701° 안에서 일치한다 — `T_ee_cam`을 믿어야 성립하지 않는 검사

### 검증 — run13 (2026-08-14, 실기)

보정이 끝난 뒤 42자세를 새로 찍어(run13, 2개 미검출) **아무것도 재적합하지
않고** `T_ee_cam.yaml`로 예측했다. 태그는 캡처 사이에 건드리지 않았다.

| | run13 코너 잔차 | 290 mm에서 |
|---|---|---|
| 전부 고정(재적합 없음) | 0.8858 px | 0.647 mm |
| `base_T_tag`만 재적합 | 0.8777 px | 0.641 mm |
| run13으로 전부 재적합(참고) | 0.8785 px | 0.642 mm |

**일반화 갭이 없다** — 학습에 안 쓴 캡처를 자기 자신을 적합한 값과 같은
정확도로 예측한다(run12 인샘플 0.8873 px). `base_T_tag`를 풀어줘도 0.008 px만
줄고, 태그가 캡처 사이에 움직인 양은 0.082 mm로 사실상 0이다.

기준 방식(sweep + depth)의 표본이 1에서 2가 됐다:

| | run12 | run13 | 차이 |
|---|---|---|---|
| `t_ee_cam` | (−5.56, −52.33, −51.90) | (−5.60, −52.40, −51.84) | **0.101 mm** |
| `R_ee_cam` | — | — | 0.144° |
| fx | 396.99 | 396.88 | 0.11 px |
| 태그 | 98.585 mm | 98.595 mm | 0.010 mm |

앞서 §6에 적힌 캡처 간 2.5 mm 스프레드는 **서로 다른 방식 조합끼리**의 차이지
기준 방식의 재현성이 아니다. 기준 방식끼리는 0.101 mm다.

### 미분(differential) 정확도 — 실사용에 해당하는 양

시퀀서는 TCP-로컬 병진만 적용하므로, 카메라 위치의 상수 오차는 상쇄되고
**자세 쌍 사이의 예측**만 문제가 된다. run13의 자세 쌍으로 잰 값:

| 쌍 | TCP 이동 | 자세 변화 | 오차 |
|---|---|---|---|
| 24 | 25–60 mm | 동일(<2°) | 0.435 px = **0.329 mm** |
| 68 | 60 mm 초과 | 동일(<2°) | 1.304 px = 0.931 mm |
| 169 | 25 mm 미만 | 무관(회전 뷰 포함) | 0.828 px = 0.598 mm |

동일 자세 25–60 mm 이동에서 0.435 px인데, 검출기 잡음만으로도
0.274·√2 = 0.387 px가 나온다. **보정이 기여하는 몫은 잡음 바닥 수준이다.**
60 mm를 넘으면 0.931 mm로 커지는데 이는 §4의 매끄러운 FK 오차장 그대로다.

한계: 이 수집의 스케줄에는 "작은 이동 + 동일 자세" 쌍이 없어(회전 뷰는 각도가
크고 sweep 뷰는 이동이 크다) 실제 보정 기하(수 mm 순수 병진)가 **직접 표집되지
않았다.** 위 0.329 mm는 그 경우의 상한으로 읽어야 한다.

이후 `handeye_probe_frame`이 관측한 `probe x`/`probe y` 두 자세(home에서 툴
x·y로 각 20 mm, 자세 불변)를 표본에 남기도록 고쳤다. 지금까지는 image
Jacobian을 뽑는 데만 쓰고 버렸는데, 그게 정확히 이 표에 없는 기하다. **다음
수집부터** 채워지므로, 이 표의 값은 아직 그 이전 데이터다.

### sweep 뷰에 대하여

sweep만으로 풀면 카메라가 (−6094, −1077, 3372) ± 3000 mm로 발산한다. 순수
병진은 AX = XB에 아무 말도 못 하기 때문이다. 그러나 회전 뷰와 **함께** 넣으면
fx σ 1.98 → 0.86, t_z σ 1.25 → 0.49로 조인다. `calibrateHandEye`에서 해로운
뷰가 FK 구속 풀이에서는 정보를 낸다.

단, 회전 뷰로 적합한 모델이 sweep 뷰 코너를 3.18 px 어긋나게 예측한다(각
그룹의 자기 적합은 0.61 / 0.63 px). 한 렌즈 모델이 화면 중앙과 모서리를 동시에
설명하지 못한다는 뜻이고, 위 §4의 결론(팔)과 함께 읽어야 한다.

## 7. 미해결

- [ ] 시트 재마운팅 후 재수집 — 비평면 0.8 mm RMS는 문서 자체 한계선
- [ ] 캘리퍼로 1페이지 100 mm 자눈금 확인
- [ ] 엔드투엔드 폐루프 검증(측정 → **보정 적용** → 재측정으로 잔차 감소 확인).
      run13은 out-of-sample 예측까지 확인했을 뿐 보정을 실제로 적용해보지는
      않았다. 비전 노드가 없어 지금은 구현 불가
- [ ] 순수 병진 쌍: `probe x`/`probe y`(20 mm, 자세 불변)를 표본에 남기도록
      고쳤으나 **아직 그 코드로 수집한 적이 없다.** 다음 수집에서 확인
- [ ] 10 mm 홀더 태그·근거리(70~150 mm) 외삽 검증. 보정은 100 mm 태그·294 mm
      에서 했다
- [ ] URDF에 카메라 링크 추가(`vision_correction_plan.md:299`)
- [x] 축별 축퇴 게이트 — `solve_joint.py`의 `gate()`가 축별 σ를
      `vision.max_correction`(3.0 mm)과 비교하고 초과 시 exit 2. 기준 수집은
      (0.427, 0.413, 0.488) mm로 통과하고, sweep 뷰 12개만 남긴 축퇴 사례에서는
      (3226, 3012, 2669) mm로 발화하는 것까지 확인
- [ ] UR3e 절대 정확도 0.59 mm — 기구학 보정은 별개 작업

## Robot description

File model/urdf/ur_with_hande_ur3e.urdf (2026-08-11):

<?xml version="1.0" ?>
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
<robot name="ur">
  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
  <link name="world"/>
  
  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
  <link name="base_link"/>
  <link name="base_link_inertia">
    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
    <inertial>
      <mass value="2.0"/>
      <origin rpy="0 0 0" xyz="0 0 0"/>
      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
    </inertial>
  </link>
  <link name="shoulder_link">
    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
    <inertial>
      <mass value="2.0"/>
      <origin rpy="0 0 0" xyz="0 0 0"/>
      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
    </inertial>
  </link>
  <link name="upper_arm_link">
    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
    <inertial>
      <mass value="3.42"/>
      <origin rpy="0 1.5707963267948966 0" xyz="-0.121825 0.0 0.12"/>
      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
    </inertial>
  </link>
  <link name="forearm_link">
    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
    <inertial>
      <mass value="1.26"/>
      <origin rpy="0 1.5707963267948966 0" xyz="-0.1066 0.0 0.027"/>
      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
    </inertial>
  </link>
  <link name="wrist_1_link">
    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
    <inertial>
      <mass value="0.8"/>
      <origin rpy="0 0 0" xyz="0 0 0"/>
      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
    </inertial>
  </link>
  <link name="wrist_2_link">
    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
    <inertial>
      <mass value="0.8"/>
      <origin rpy="0 0 0" xyz="0 0 0"/>
      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
    </inertial>
  </link>
  <link name="wrist_3_link">
    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
    <inertial>
      <mass value="0.35"/>
      <origin rpy="0 0 0" xyz="0.0 0.0 -0.02"/>
      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
    </inertial>
  </link>
  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
  <joint name="base_joint" type="fixed">
    <origin rpy="0 0 0" xyz="0 0 0"/>
    <parent link="world"/>
    <child link="base_link"/>
  </joint>
  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
  <joint name="base_link-base_link_inertia" type="fixed">
    <parent link="base_link"/>
    <child link="base_link_inertia"/>
    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
    <origin rpy="0 0 3.141592653589793" xyz="0 0 0"/>
  </joint>
  <joint name="shoulder_pan_joint" type="revolute">
    <parent link="base_link_inertia"/>
    <child link="shoulder_link"/>
    <origin rpy="0 0 0" xyz="0 0 0.15185"/>
    <axis xyz="0 0 1"/>
    <limit effort="56.0" lower="-6.283185307179586" upper="6.283185307179586" velocity="3.141592653589793"/>
    <dynamics damping="0" friction="0"/>
  </joint>
  <joint name="shoulder_lift_joint" type="revolute">
    <parent link="shoulder_link"/>
    <child link="upper_arm_link"/>
    <origin rpy="1.570796327 0 0" xyz="0 0 0"/>
    <axis xyz="0 0 1"/>
    <limit effort="56.0" lower="-6.283185307179586" upper="6.283185307179586" velocity="3.141592653589793"/>
    <dynamics damping="0" friction="0"/>
  </joint>
  <joint name="elbow_joint" type="revolute">
    <parent link="upper_arm_link"/>
    <child link="forearm_link"/>
    <origin rpy="0 0 0" xyz="-0.24355 0 0"/>
    <axis xyz="0 0 1"/>
    <limit effort="28.0" lower="-3.141592653589793" upper="3.141592653589793" velocity="3.141592653589793"/>
    <dynamics damping="0" friction="0"/>
  </joint>
  <joint name="wrist_1_joint" type="revolute">
    <parent link="forearm_link"/>
    <child link="wrist_1_link"/>
    <origin rpy="0 0 0" xyz="-0.2132 0 0.13105"/>
    <axis xyz="0 0 1"/>
    <limit effort="12.0" lower="-6.283185307179586" upper="6.283185307179586" velocity="6.283185307179586"/>
    <dynamics damping="0" friction="0"/>
  </joint>
  <joint name="wrist_2_joint" type="revolute">
    <parent link="wrist_1_link"/>
    <child link="wrist_2_link"/>
    <origin rpy="1.570796327 0 0" xyz="0 -0.08535 -1.750557762378351e-11"/>
    <axis xyz="0 0 1"/>
    <limit effort="12.0" lower="-6.283185307179586" upper="6.283185307179586" velocity="6.283185307179586"/>
    <dynamics damping="0" friction="0"/>
  </joint>
  <joint name="wrist_3_joint" type="revolute">
    <parent link="wrist_2_link"/>
    <child link="wrist_3_link"/>
    <origin rpy="1.570796326589793 3.141592653589793 3.141592653589793" xyz="0 0.0921 -1.8890025766262e-11"/>
    <axis xyz="0 0 1"/>
    <limit effort="12.0" lower="-6.283185307179586" upper="6.283185307179586" velocity="6.283185307179586"/>
    <dynamics damping="0" friction="0"/>
  </joint>
  <link name="ft_frame"/>
  <joint name="wrist_3_link-ft_frame" type="fixed">
    <parent link="wrist_3_link"/>
    <child link="ft_frame"/>
    <origin rpy="3.141592653589793 0 0" xyz="0 0 0"/>
  </joint>
  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
  <link name="base"/>
  <joint name="base_link-base_fixed_joint" type="fixed">
    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
    <origin rpy="0 0 3.141592653589793" xyz="0 0 0"/>
    <parent link="base_link"/>
    <child link="base"/>
  </joint>
  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
  <link name="flange"/>
  <joint name="wrist_3-flange" type="fixed">
    <parent link="wrist_3_link"/>
    <child link="flange"/>
    <origin rpy="0 -1.5707963267948966 -1.5707963267948966" xyz="0 0 0"/>
  </joint>
  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
  <link name="tool0"/>
  <joint name="flange-tool0" type="fixed">
    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
    <origin rpy="1.5707963267948966 0 1.5707963267948966" xyz="0 0 0"/>
    <parent link="flange"/>
    <child link="tool0"/>
  </joint>
  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
  <joint name="robotiq_hande_coupler_joint" type="fixed">
    <origin rpy="-1.5707963267948966 0 -1.5707963267948966" xyz="0 0 0"/>
    <parent link="flange"/>
    <child link="robotiq_hande_coupler"/>
  </joint>
  <link name="robotiq_hande_coupler">
    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
    <inertial>
      <mass value="0.119"/>
      <origin rpy="0 0 0" xyz="0 0 0.005449999999999999"/>
      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
    </inertial>
  </link>
  <joint name="robotiq_hande_base_joint" type="fixed">
    <origin rpy="0 0 0" xyz="0 0 0.011"/>
    <parent link="robotiq_hande_coupler"/>
    <child link="robotiq_hande_link"/>
  </joint>
  <link name="robotiq_hande_link">
    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
    <inertial>
      <mass value="0.86387"/>
      <origin rpy="0 0 0" xyz="0 0 0.0495"/>
      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
    </inertial>
  </link>
  <joint name="robotiq_hande_left_finger_joint" type="prismatic">
    <origin rpy="0 0 0" xyz="0 0 0.099"/>
    <parent link="robotiq_hande_link"/>
    <child link="robotiq_hande_left_finger"/>
    <axis xyz="1 0 0"/>
    <limit effort="130" lower="0.0" upper="0.025" velocity="0.15"/>
  </joint>
  <link name="robotiq_hande_left_finger">
    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
    <inertial>
      <origin rpy="0 0 0" xyz="0 0 0"/>
      <mass value="0.03804"/>
      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
    </inertial>
  </link>
  <joint name="robotiq_hande_right_finger_joint" type="prismatic">
    <origin rpy="0 0 0" xyz="0 0 0.099"/>
    <parent link="robotiq_hande_link"/>
    <child link="robotiq_hande_right_finger"/>
    <axis xyz="-1 0 0"/>
    <limit effort="130" lower="0.0" upper="0.025" velocity="0.15"/>
    <mimic joint="robotiq_hande_left_finger_joint" multiplier="1" offset="0"/>
  </joint>
  <link name="robotiq_hande_right_finger">
    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
    <inertial>
      <origin rpy="0 0 0" xyz="0 0 0"/>
      <mass value="0.03804"/>
      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
    </inertial>
  </link>
  <joint name="robotiq_hande_end_joint" type="fixed">
    <origin rpy="0 0 0" xyz="0 0 0.14550000000000002"/>
    <parent link="robotiq_hande_link"/>
    <child link="robotiq_hande_end"/>
  </joint>
  <link name="robotiq_hande_end"/>
</robot>

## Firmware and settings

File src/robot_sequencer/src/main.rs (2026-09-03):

//! robot-sequencer: the EPICS-triggered sample-changer daemon, ROS-free.
//!
//! Replaces the `epics_triggered_sequence` C++ node plus the UR ROS
//! driver, MoveIt, and the stage-scene/ACM setup nodes: epics-ca-rs
//! talks CA to the (unchanged) robot_ioc, cspace plans, ur-driver
//! executes, robotiq-hande drives the gripper directly.
//!
//! Usage: `robot-sequencer <config/sequencer.yaml>`
//!
//! On daemon death (crash or Ctrl-C) the robot's external-control
//! program loses its reverse-interface connection and halts motion; the
//! IOC keeps `CurrentStep`, so the operator resumes per the
//! resume-after-crash procedure in CLAUDE.md.

mod config;
mod epics;
mod error;
mod gripper;
mod handeye;
mod log;
mod model;
mod motion;
mod seatcheck;
mod sequence;
mod stream;
mod waypoints;

use std::path::PathBuf;
use std::process::ExitCode;

use crate::config::Config;
use crate::epics::{Epics, NullReport, NullState};
use crate::error::SequencerError;
use crate::gripper::Gripper;
use crate::model::Model;
use crate::motion::Motion;
use crate::seatcheck::HandEye;
use crate::sequence::Sequencer;

fn run() -> Result<(), SequencerError> {
    let config_path: PathBuf = std::env::args_os()
        .nth(1)
        .ok_or_else(|| SequencerError("usage: robot-sequencer <config.yaml>".into()))?
        .into();
    let config = Config::load(&config_path)?;

    log::info("Loading robot model...");
    let model = Model::load(&config)?;

    let seat_check = config
        .seat_check
        .enabled
        .then(|| HandEye::load(&config.seat_check.hand_eye_yaml))
        .transpose()?;
    let epics = Epics::connect(
        &config.epics,
        config.vision.enabled.then_some(&config.vision),
        config.seat_check.enabled.then_some(&config.seat_check),
    )?;
    // A trigger left at 1 by a crash must not fire a sequence the moment
    // the daemon returns; clearing it is the C++ node's startup behavior.
    epics.write_trigger(0);
    // Same reasoning for the grip null's status: the result on the
    // screen belongs to a run this daemon is no longer in, so it is
    // cleared rather than left to look current.
    epics.publish_null(&NullReport {
        state: NullState::Idle,
        iteration: 0,
        total_mm: [0.0; 3],
        force_n: 0.0,
        message: String::new(),
    });

    let motion = Motion::connect(&model, &config)?;
    let gripper = Gripper::connect(&config)?;

    log::info("========================================");
    log::info("EPICS Triggered Sequence Ready");
    log::info("========================================");
    log::info(&format!("  Trigger PV: {}", config.epics.trigger_pv));
    log::info(&format!("  StartStep PV: {}", config.epics.start_step_pv));
    log::info(&format!(
        "  Wait PV: {} (0=wait, 1=continue, 2=skip)",
        config.epics.wait_pv
    ));
    log::info(&format!("  Holder PV: {} (1-10)", config.epics.holder_pv));
    log::info(&format!(
        "  Stop PV: {} (1=pause, 0=resume)",
        config.epics.stop_pv
    ));
    log::info(&format!(
        "  CurrentStep PV: {} (updated after each step)",
        config.epics.current_step_pv
    ));
    log::info(&format!(
        "  Gripper PV: {} (command: 0=close, 1=open)",
        config.epics.gripper_pv
    ));
    log::info(&format!(
        "  Gripper_RBV PV: {} (status, threshold={:.3})",
        config.epics.gripper_rbv_pv, config.gripper.open_threshold
    ));
    log::info(&format!(
        "  PauseStep PV: {} (N=pause after step N until changed)",
        config.epics.pause_step_pv
    ));
    log::info(&format!("  CalibMode PV: {}", config.epics.calib_mode_pv));
    log::info("    0=Normal (full sequence)");
    log::info("    1=Holder calibration (0-5, wait, 20-23)");
    log::info("    2=SampleHolder calibration (0-8, wait, 16-23)");
    log::info("    3=Hand-eye calibration (trigger, jog to aim, trigger again; tool rotations");
    log::info(&format!(
        "      ±{:.0} deg in place -> {}/samples_<timestamp>.yaml)",
        config.handeye.angle_deg,
        config.handeye.out_dir.display()
    ));
    log::info("    4=Recover (return the arm to holder standby; gripper untouched)");
    log::info("    5=Seat probe (trigger, jog the gripped puck into the seat, trigger again;");
    log::info(&format!(
        "      steps into contact at {:.2}/{:.2} N, measures, writes nothing)",
        config.probe.bore.lateral.threshold_n, config.probe.bore.depth.threshold_n
    ));
    log::info("    6=Grip null (pick and reseat a puck at this seat, writing the trims");
    log::info(&format!(
        "      the close wrench asks for, until it settles under {} N or {} tries;",
        config.grip_null.settled_n, config.grip_null.max_iterations
    ));
    log::info(&format!(
        "      {} fetches the puck from a rack holder first, 0 uses the seat's own;",
        config.epics.map_source_pv
    ));
    log::info(&format!(
        "      {}=0 nulls the stage instead of a rack seat, fetch included)",
        config.epics.holder_pv
    ));
    log::info("    7=Holder transfer (carry the puck straight to the target seat;");
    log::info(&format!(
        "      source holder from {}, no stage leg and no probe)",
        config.epics.map_source_pv
    ));
    if config.vision.enabled {
        log::info(&format!(
            "  Vision correction: ENABLED{} (deadband {:.2} mm, limit {:.2} mm, {})",
            if config.vision.observe_only {
                " [observe_only]"
            } else {
                ""
            },
            config.vision.min_correction,
            config.vision.max_correction,
            config.vision.req_pv
        ));
    }
    if let Some(eye) = &seat_check {
        let t = eye.ee_t_cam.translation.vector * 1000.0;
        log::info(&format!(
            "  Seat check: ENABLED ({}, camera at ({:.1}, {:.1}, {:.1}) mm on the tool, \
             solved at fx {:.1})",
            config.seat_check.hand_eye_yaml.display(),
            t.x,
            t.y,
            t.z,
            eye.colour.k[0]
        ));
    }
    log::info("========================================");

    Sequencer::new(epics, motion, gripper, &model, &config, seat_check).run()
}

fn main() -> ExitCode {
    match run() {
        Ok(()) => ExitCode::SUCCESS,
        Err(e) => {
            log::error(&e.to_string());
            ExitCode::FAILURE
        }
    }
}

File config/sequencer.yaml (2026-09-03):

# robot-sequencer configuration.
#
# Paths are resolved relative to this file's directory unless absolute.
# Values mirror the parameters of the replaced ROS node
# (epics_triggered_sequence) and its production launcher
# (desktop/scripts/launch_epics_sequence.sh).

robot:
  ip: "192.168.192.10"           # UR3e; URSim rehearsal: 192.168.56.101
  urdf: "../model/urdf/ur_with_hande_ur3e.urdf"
  srdf: "../model/srdf/ur.srdf"
  mesh_packages:
    ur_description: "../model/meshes/ur_description"
    robotiq_hande_description: "../model/meshes/robotiq_hande_description"
  group: "ur_manipulator"
  ik_frame: "robotiq_hande_end"
  script_file: "../resources/urscript/external_control.urscript"
  output_recipe: "../resources/urscript/rtde_output_recipe.txt"
  input_recipe: "../resources/urscript/rtde_input_recipe.txt"
  rtde_frequency_hz: 50.0        # state reads only; trajectories go out
                                 # over the trajectory interface. Lower is
                                 # safer: unread packages fill the 131 KB
                                 # socket buffer in 0.5 s at 500 Hz and
                                 # URControl drops the client. Does not
                                 # change the servoj period.

# Planning-time joint limit overrides, ported from
# ur3e_hande_moveit_config/config/joint_limits.yaml. URDF carries no
# acceleration limits and TOTG requires them. Position overrides
# (+-pi on the three non-continuous joints) match the MoveIt config;
# the joints MoveIt marked continuous keep the URDF's +-2pi bounds
# (documented deviation: a strict subset of "continuous", and every
# taught waypoint lies inside it).
joint_limits:
  max_velocity: 3.14159          # rad/s, all six arm joints
  max_acceleration: 1.0          # rad/s^2, all six arm joints
  position_overrides:
    shoulder_lift_joint: [-3.14159, 3.14159]
    elbow_joint: [-3.14159, 3.14159]
    wrist_2_joint: [-3.14159, 3.14159]

epics:
  trigger_pv: "Robot:Trigger"
  start_step_pv: "Robot:StartStep"
  wait_pv: "Robot:Wait"
  holder_pv: "Robot:Holder"
  stop_pv: "Robot:Stop"
  current_step_pv: "Robot:CurrentStep"
  gripper_pv: "Robot:Gripper"
  gripper_rbv_pv: "Robot:Gripper_RBV"
  pause_step_pv: "Robot:PauseStep"
  calib_mode_pv: "Robot:CalibMode"
  loaded_pv: "Robot:Loaded"
  jog_x_pv: "Robot:JogX"
  jog_y_pv: "Robot:JogY"
  jog_z_pv: "Robot:JogZ"
  jog_step_pv: "Robot:JogStep"
  map_source_pv: "Robot:MapSource"

sequence:
  waypoints_yaml: "taught_waypoints.yaml"
  holder_offset: 0.03            # m between holders in Y
  velocity_scale: 1.0
  acceleration_scale: 1.0
  cartesian_translation_step: 0.005   # m, 5 mm interpolation resolution
  cartesian_rotation_step: 0.05       # rad
  cartesian_min_fraction: 0.95        # below this: fall back to planned move
  jog_velocity_scale: 0.1             # calibration jog runs slow
  cartesian_velocity_scale: 0.2       # extra scale on every Cartesian step
                                      # (the approach/insert/extract legs
                                      # around the rack and the stage). The
                                      # planned transits (steps 1/7/18)
                                      # keep velocity_scale.

  # Keep the gripper level through joint-space plans (steps 7 and 18).
  # Those two only constrain the goal, so the planner is free to roll the
  # tool over on the way; measured on the robot, the 63-degree holder-to-
  # stage move swung it to vertical. Cartesian steps interpolate the pose
  # and never had the problem.
  #
  # The constraint is "approach axis stays horizontal", not "orientation
  # stays fixed": the holder is approached along -Y and the stage along
  # +X, 92 degrees apart, so rotation within the horizontal plane must
  # stay free. The taught poses are themselves 1.64 and 0.84 degrees off
  # level, leaving ~1.4 degrees of margin at 3.0.
  level_tool:
    enabled: true
    tolerance_deg: 3.0
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

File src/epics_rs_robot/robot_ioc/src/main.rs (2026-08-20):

//! Rust soft-record IOC for the UR3e + Robotiq Hand-E robot.
//!
//! Replaces `softIoc -d db/robot.db` (EPICS base is not installed on this host).
//! Serves the `Robot:*` PVs over Channel Access for `robot_gui`, the CA↔ROS2
//! bridge, and any other CA client. The existing `ws/db/robot.db` is reused
//! unchanged — all records are plain soft records (bo/mbbo/longout/longin/bi/ao).
//!
//! Usage:
//!   robot_ioc [path/to/st.cmd]
//! With no argument it runs the bundled `ioc/st.cmd`.

use std::sync::{Arc, Mutex};

use epics_base_rs::error::CaResult;
use epics_base_rs::server::autosave::startup::AutosaveStartupConfig;
use epics_ca_rs::server::ioc_app::IocApplication;
use epics_ca_rs::server::run_ca_ioc;

#[epics_base_rs::epics_main]
async fn main() -> CaResult<()> {
    // Default the macros used by st.cmd. Override by exporting them before launch.
    //
    // Both defaults are relative to the checkout this binary was built
    // from, so a hand-run serves that tree's own db rather than another
    // one's. The absolute /home/bl9b/ws/db this used to name is a copy
    // with no CalibMode 3-7 labels and no Robot:MapSource, so a binary
    // built in the sample-changer repo would come up missing the records
    // grip null and holder transfer steer by -- and say nothing about it.
    // systemd passes ROBOT_DB explicitly regardless (see deploy/).
    epics_base_rs::runtime::env::set_default(
        "ROBOT_DB",
        concat!(env!("CARGO_MANIFEST_DIR"), "/../../../db"),
    );
    epics_base_rs::runtime::env::set_default("ROBOT_IOC", env!("CARGO_MANIFEST_DIR"));

    let args: Vec<String> = std::env::args().collect();
    let script = if args.len() > 1 && !args[1].starts_with('-') {
        args[1].clone()
    } else {
        format!("{}/ioc/st.cmd", env!("CARGO_MANIFEST_DIR"))
    };

    // Autosave so the robot run-state PVs (CurrentStep/Holder/CalibMode/Loaded/
    // StartStep) survive an IOC or power restart — this is what makes resume-after-
    // crash possible. The .req/.sav paths are configured in st.cmd.
    let autosave_config = Arc::new(Mutex::new(AutosaveStartupConfig::new()));

    IocApplication::new()
        .autosave_startup(autosave_config)
        .startup_script(&script)
        .run(run_ca_ioc)
        .await
}

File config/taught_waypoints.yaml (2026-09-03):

/**:
  ros__parameters:
    holder1_standby: [0.024705882352941178, -1.2054403463946741, 0.006688363384455442,
      -1.207269016896383, -3.4068523846068324, -1.6373335123062134, -1.253219024544098]
    holder1_on_position: [0.024705882352941178, -1.3271001021014612, 6.194162415340543e-05,
      -1.3306644598590296, -3.3016468487181605, -1.3807628154754639, -1.6005197964110316]
    sample_holder_standby: [0.024705882352941178, -0.17618304887880498, 0.0090628145262599,
      -1.7623332182513636, -2.3054896793761195, -2.479313373565674, -1.4844883319786568]
    sample_holder_on_position: [0.003333333333333334, -0.09870034853090459, 0.007620103191584349,
      -1.6875322500811976, -2.418257852593893, -1.8540196418762207, -1.9946166477599085]
    above_y_offset: -0.005
    retreat_z_offset: -0.05
    # The rack's own base correction, m: applied to every holder pose
    # before the per-holder step. NOT holder 1's trim -- holder 1 has
    # its own entry at index 0 of the holder_multi_* lists below.
    holder_rack_x_offset: 0.0
    holder_rack_y_offset: 0.0005
    holder_on_position_lift: 0.00015
    holder_on_position_tilt_x_deg: 0.3
    # The other lean axis, about tool z (base +y), deg. Spin about the
    # puck's own axis is wrist3_rotation_offset, not a tilt.
    holder_on_position_tilt_z_deg: 0.0
    holder_rack_z_offset: -0.0003
    sample_holder_on_position_x_offset: -0.0112096
    sample_holder_on_position_y_offset: -0.002
    sample_holder_on_position_z_offset: 0.0046552
    # Per-holder trims, holder N at index N-1 -- holder 1 included, so
    # trimming it moves it and nothing else.
    holder_multi_x_offsets: [-0.0002067, 9.18e-5, 0.0003947, 0.001, 0.0006846, 0.0012567, 0.0011608, 0.0012759, 0.0016128, 0.002034]
    # Insertion-depth trim, tool y (base -z), m, holder N at index N-1;
    # positive is deeper.
    holder_multi_y_offsets: [0.0, 0.0, 0.0, 0.0, 0.0, 0.0, 0.0, 0.0, 0.0, 0.0]
    # h8/h9 z are EXTRAPOLATED, not probed: h1-h7 fit z = 0.7357 - 0.1888*N mm
    # with 0.025 mm RMS (2026-08-19). h10 is measured, but by nulling the
    # gripper-close wrench rather than by the seat probe -- the probe reads
    # walls the pinned puck is already touching, the close reads the pose
    # error itself (2026-08-19).
    holder_multi_z_offsets: [0.0005545, 0.0003259, 0.000206, -1.4e-5, -0.0002204, -0.0004312, -0.0005983, -0.0007872, -0.0009831, -0.0010652]
    # Per-holder trim on holder_on_position_tilt_x_deg, deg, holder N at
    # index N-1. Reloaded every trigger, like everything here.
    holder_multi_tilt_x_deg: [0.0, 0.0, 0.0, 0.0, 0.0, 0.0, 0.0, 0.0, 0.0, 0.0]
    # Per-holder trim on holder_on_position_tilt_z_deg, deg, same shape.
    holder_multi_tilt_z_deg: [0.0, 0.0, 0.0, 0.0, 0.0, 0.0, 0.0, 0.0, 0.0, 0.0]
    wrist3_rotation_offset: 0.0

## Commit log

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2026-06-01 EPICS layer overhaul: Rust IOC, libca node, sequence safety fixes
    - Fix Hand-E activation: set libmodbus response timeout to 2s (UR tool-comm
    first-transaction warm-up ~480ms exceeds the 500ms default); remove the
    double-socat conflict (create_socat_tty=false) and fix socat_ip_address.
    - Fix ur_moveit_config Python module install path (ament_python_install_package).
    - Fix latent MoveIt Plan.trajectory_ build error in epics_triggered_sequence.
    - Add Rust epics-rs soft IOC (epics_rs_robot/robot_ioc) serving robot.db over CA,
    with autosave (state persistence) and procServ/systemd boot autostart (deploy/).
    - C++ sequence node links libca directly (~/epics-base, baked rpath).
    - Sequence saf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
    [ur_with_hande.xacro]
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2026-08-11 model/config: add static robot description and sequencer configuration
    Generated URDFs (ur3e for the beamline, ur5e for URSim rehearsal) with
    ros2_control stripped, the MoveIt SRDF, collision meshes, and one master
    sequencer.yaml carrying what used to be spread across launch args,
    joint_limits.yaml, stage_scene_utils and setup_stage_acm.py. The taught
    waypoint YAML is copied unchanged so calibrated values carry over.
    [base.stl, finger_assembly.stl, forearm.stl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]
2026-08-11 robot_sequencer: port EPICS sequence daemon to Rust (ur-driver + cspace)
    Replaces epics_triggered_sequence + UR ROS driver + MoveIt with one
    daemon: epics-ca-rs polls the unchanged robot_ioc PVs, cspace plans
    (RRT-Connect + TOTG) and interpolates Cartesian lines, ur-driver streams
    spline points over the trajectory interface, robotiq-hande drives the
    gripper directly. Step tables, calibration modes, jog, settle-wait and
    the exit-on-failure resume semantics (CurrentStep preserved) follow the
    C++ node; deps resolve to sibling checkouts (ur-rs, cspace, epics-rs).
    [main.rs]
2026-08-11 src: remove ROS packages replaced by robot_sequencer
    Everything the daemon absorbed goes: epics_robot, the UR/MoveIt/Hand-E
    description and driver packages, stage_scene_utils, MTC, serial, and
    realsense_service (the vision-plan doc's camera service will need a
    ROS-free port when that work starts). Launchers collapse to [1]
    sequencer + [2] GUI; robot_ioc stays on systemd. The GUI's waypoint
    file dialog now defaults to ~/ws/config, where taught_waypoints.yaml
    lives after epics_robot's removal.
    [2f_140.ros2_control.xacro, 2f_85.ros2_control.xacro, camera_mount.xacro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]
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2026-08-11 config: add URSim rehearsal variant of the sequencer configuration
    ur5e model and simulated gripper because URSim has no RS485 tool
    device; no stage scene because the beamline-cell mesh around the
    ur3e would collide the longer ur5e at the taught targets.
    [sequencer_ursim.yaml]
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2026-08-11 sequencer: add wrist-camera fine-correction hooks to the normal sequence
    Look-then-move at the four above->on descents plus grip-offset and
    seating checks, over a Robot:Vision:* PV handshake. Corrections are
    TCP-local IK offsets gated by norm: sub-deadband ignored, over-limit
    stops the daemon instead of auto-applying. Request ids seed from the
    Done echo persisted in the IOC so a stale ack from a previous daemon
    run cannot alias a fresh request. Disabled by default; vision.enabled
    false leaves the sequence unchanged.
    [main.rs, sequencer.yaml]
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2026-08-13 motion: keep the tool level, and stop streaming RTDE through planning
    Two fixes to the joint-space steps, in the same files because both
    live in `Motion::plan`'s path.
    Level tool. Joint-space planning only constrained the goal, so
    RRT-Connect was free to roll the tool over on the way there: the
    63-degree move between the holder and the stage swung the gripper to
    vertical mid-path, carrying a sample. `path_constraints` now pins the
    approach axis to the horizontal plane. Not to a fixed orientation —
    the holder is approached along -Y and the stage along +X, 92 degrees
    apart, so rotation within that plane has to stay free.
    Two things about that constraint are easy to get wrong and were:
    -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
    [sequencer_nostage.yaml, sequencer_ursim.yaml]
2026-08-13 scene: replace the stage CAD mesh with a convex decomposition
    The stage shipped as its full-fidelity CAD export, 231,812 triangles.
    That cost 120-154 s of parsing and BVH build at every daemon start —
    the reason iterating on the robot took two and a half minutes a
    round — and ~930 ms of every joint-space plan, essentially all of it
    collision queries against that mesh: planning the same move with the
    stage removed takes 62 ms.
    tools/stage_collision reduces it in two steps, both measured against
    the CAD mesh before being adopted:
    Crop to what a UR3e can reach. 46% of the mesh — the support structure
    below the table, the far end of the stage — sits beyond 0.8 m of the
    base and cannot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
    [stage_part00.stl, stage_part01.stl, stage_part02.stl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]
2026-08-13 motion: make the RTDE stream a borrow, and split motion.rs by interface
    Two bugs this session came from the same place: bring-up returned with
    the RTDE stream running and the Hand-E activation read nothing for
    1.4 s; `fresh_q` returned with it running and planning read nothing for
    a second. URControl drops a client that stops reading, so both times
    the daemon lost the robot — and both times it surfaced as an RTDE error
    at the *next* step, never at the code that caused it. Both fixes were a
    `pause` call at a call site that had to remember to make it, and
    `sequence.rs` carried five more of those.
    So the stream is no longer something a caller turns on. `RtdeStream`
    hands out a `Session` that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
    [main.rs]
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2026-08-14 handeye: give every capture its own samples file
    `handeye_capture` wrote a fixed `samples.yaml`, so a second capture
    replaced the first with no warning and no copy — which happened, and the
    poses behind the calibration of record survived only because they had
    been copied aside by hand. The name now carries a timestamp; `aim_pose`
    keeps its fixed path, since replacing the last aim is what a capture is
    supposed to do. CLAUDE.md still named `solve.py` and `handeye.python`
    here, a site the interpreter split missed.
    [main.rs, sequencer.yaml]
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2026-08-14 sequence: observe the vision hooks from standby, not from above
    Each hook measured at the pose it corrects, where the grasp point
    projects 55 rows below a 480-row frame and the disc filling the middle
    belongs to the next holder up. Measuring somewhere other than where the
    correction lands is why Correction now carries its observation frame.
    Grip offset stays where it was: the puck rides with the tool, so no
    pose brings it further into view.
    [sequencer.yaml, sequencer_nostage.yaml]
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2026-08-14 vision: raise min_correction above the arm's own re-approach spread
    Twenty production cycles put the observation pose's re-approach at sigma
    (0.022, 0.007) mm and peak-to-peak (0.095, 0.026) mm, twenty times the
    estimator's floor. The old 0.05 mm sat inside that spread, so one cycle in
    twenty would have been corrected for nothing; §12.3's 0.070 mm, the single
    sample that set the earlier expectation, was larger than any of the twenty.
    [sequencer.yaml, sequencer_nostage.yaml]
2026-08-14 vision: add the node that answers the sequencer's measurement requests
    The two kinds it cannot measure answer Valid=0 rather than zeros: a zero
    correction reads as "aligned", passes the deadband, and is indistinguishable
    from a real answer, so both configs turn those hooks off instead of letting
    the node invent one. Kind alone cannot key a reference — Pick Align fires at
    steps 1 and 12 on different scenes — and CurrentStep is already published by
    the time the hook runs, so the key is built from it.
    [sequencer.yaml, sequencer_nostage.yaml]
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2026-08-15 motion: step into contact, and bracket the seat from it
    Whether the offsets are right is a question about force — a puck that
    rubs on the way in shakes the sample — and image agreement is a proxy
    that cannot see a bore whose axis differs from its rim. Stepping and
    reading force between steps rather than cancelling a slow trajectory
    is what puts the threshold at 0.5 N instead of above the 1 N that
    moving alone costs, and it bounds the overshoot at one step by
    construction. The answer does not carry the threshold: laterally the
    midpoint of two walls cancels it, vertically the force-versus-depth
    fit extrapolates past it.
    CalibMode 5 measures and reports; nothing is written back into the
    wa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
    [probe.rs, sequencer.yaml]
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2026-08-15 motion: stop TOTG from throwing away a probe step
    Time parameterisation drops a waypoint when no joint moved further
    than min_angle_change, upstream's guard against repeated planner
    points; a trajectory left with one point executes as a trivial
    success, so the move is reported complete and never sent. On the arm
    0.05 and 0.10 mm jogs travelled exactly 0.000 mm. The threshold is
    pose-dependent — 0.20 mm is 1.03e-3 rad at holder1_standby and
    7.5e-4 rad at sample_holder_on_position — so a larger step is not a
    fix, and jog_fine passes FINE_MIN_ANGLE_CHANGE instead.
    [probe.rs]
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2026-08-15 probe: guard the probe by contact, not by a scene with no bore
    The stage is an approximate convex decomposition, so thin concavities
    fill in; the config already says holder1_on_position reads as a
    collision because of it. The probe borrowed the operator jog's scene
    gate, so at the seated pose it exists to measure, every step was
    refused at 0.0% — measured on the arm, including a 2 mm jog straight
    up and out of the bore, because the start state itself is inside
    filled-in geometry.
    Guard names what makes each straight-line move safe, and probe_step
    replaces jog_fine rather than adding a flag to it: a jog and a probe
    step are different motions that share a mechanism. The return is now
    a retr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
    [probe.rs]
2026-08-15 probe: open the fingers before the seat probe steps
    A gripped puck closes the gripper-puck-bore loop, so every step measured
    how hard the arm deforms it rather than how far the puck can move.
    `wait_reached` cannot put the play back: `reach_tolerance` is 1.5 mm
    against a 0.3 mm move, so it returns before the fingers have gone
    anywhere, which is also why the position the close reports (0.0095 m) is
    not where they stop (0.0037 m). `settle_to` waits for the stall instead,
    and `with_grip_loosened` owns the restore so an abort cannot leave a
    sample hanging in a loosened grip.
    [sequencer.yaml]
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2026-08-18 probe: give the fingers 1.2 mm of play, not 0.3
    Half the play is the free run before a pad touches the puck again, so it
    has to beat the nominal 0.50 mm radial clearance for "nothing in the free
    run" to mean the fingers were not what was in the way. At 0.3 the free
    run was 0.2 mm, and base y+ still read 6.008 N — the same 6.293 N the
    clamped run gave. At 1.275 mm the same direction reads 0.652 N.
    [sequencer.yaml]
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2026-08-18 probe: 2.5 mm of play, and release at the gripper's minimum force
    At 1.2 mm every direction still met something on the first step; at 2.5
    two of the four run the full 1.50 mm at 0.15 N and the other two touch
    at 1.10 and 1.04 mm, and the depth probe finds a floor 0.91 mm down.
    The release also stops using the full force scale — it opens into a
    rack, so a release that meets the holder should stall, not push.
    [sequencer.yaml]
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2026-08-18 probe: give the lateral probe 3 mm so both walls are reachable
    At 1.5 mm two of the four lateral directions ran out with nothing in
    front of them and the bracket had no midpoint to report. The loosened
    fingers' own free run is half of loosen_mm, 1.27 mm, so the allowance
    has to clear that plus the bore clearance before "no contact" says
    anything about the metal.
    [sequencer.yaml]
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2026-08-18 probe: a force across the probe is not a wall along it
    step_until_contact judged both contact and the abort with
    along.abs().max(lateral), so a load orthogonal to the direction being
    probed recorded a wall at a travel that had nothing to do with one —
    base x- tripped on 1.037 N lateral with 0.256 N along. Reading now
    names the two judgements: contact is the probe axis alone, the abort
    is the whole force change, which is never below the max it replaces.
    [probe.rs]
2026-08-18 probe: one meaning of "where it touched", on every axis
    The floor was fitted from its force-versus-travel samples while the two
    lateral walls were read off the trip point, on the argument that a late
    threshold cancels in the midpoint. It cancels only when both sides trip
    alike, and on 2026-08-18 base x+ ramped over 0.7 mm against a steady
    drag while base x- went from noise to tripped in one step. Contact::
    wall_mm now places every wall, extrapolating the ramp back to the
    baseline the force sat at before contact rather than to zero, and a
    bracket that cannot fit both sides falls back to the trip point on
    both. Lateral contact leaves no ramp below a 0.5 N threshold, so
    overtravel_steps buys th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
    [probe.rs, sequencer.yaml]
2026-08-18 probe: the overtravel must not be what trips the abort
    Three 0.05 mm steps past the base y+ wall took the load from 2.48 N to
    5.24 N and aborted a run that had already found its contact — steps the
    probe chose to take into something it knew was there. It now stops at
    half the abort limit as well as at overtravel_steps, so a wall stiffer
    than the count was set for costs the fit samples rather than the run.
    [probe.rs, sequencer.yaml]
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2026-08-18 probe: sweep the seat probe over a ladder of heights
    A firm grip at the taught pose leaves under 0.05 mm before 8 N, so the
    bracket there measures the seat's shoulder rather than its clearance.
    The height is owned by `sweep_heights` so an abort part way up still
    lowers the arm back, and `probe_reposition` moves it because
    `Motion::jog`'s scene guard refuses every in-bore pose.
    [probe.rs]
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2026-08-18 probe: centre x and y before every vertical move
    A lift that starts off-centre spends the bore's clearance sideways: from
    the taught pose a straight 3 mm climb released the vertical preload in
    0.2 mm and then met 8.17 N laterally at +0.316 mm. Each level now ends
    by moving to the middle of the walls it measured, and `Axes`/`from_trigger`
    carry the three-axis offset so the return is one subtraction.
    [probe.rs]
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2026-08-18 probe: log the force and the off-axis travel in base components
    `lateral` is a magnitude, so a lift along base z reports 14.83 N across
    the axis without saying whether the puck is being driven in base x or in
    base y — and a force across the axis has two possible authors, the thing
    being pushed or the arm not going straight, which the drift separates.
    [probe.rs]
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2026-08-18 gripper: close on the sample at a configured force and speed
    Every close sent full scale, which on a Hand-E is 185 N arriving at
    150 mm/s onto a puck that then has to fit a bore with 0.50 mm of
    nominal radial clearance. A gripped puck has 0.05 mm of freedom in the
    seat where a free one has ten times that, so how hard it is squeezed is
    part of whether it fits, not a detail of the grip.
    [sequencer.yaml]
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2026-08-18 waypoints: lift the holder seat without moving the standby pose
    The shared holder1_on_position trim is applied to the standby pose as
    well, and standby reads as a collision against the convex stage: the
    sequence only gets away with it because step 1 finds itself already
    there and skips the move. Raising the seat through that trim moved
    standby by 0.15 mm, which was enough for step 1 to plan and fail on an
    invalid start.
    [probe.rs, taught_waypoints.yaml]
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2026-08-18 motion: give probe_reposition an execution floor over f64::EPSILON
    Sideways corrections accrue cross-term residue (~0.004 off-axis per
    base-axis unit vector) in from_trigger; return_to_trigger passed it
    on and probe_reposition commanded a 0.000 mm step, tripping the
    step-taken guard. MIN_EXECUTABLE_MM separates residue (<=0.012 mm)
    from a real centring step (0.05 mm), asserted at compile time.
    [probe.rs]
2026-08-18 waypoints: per-holder grip tilt, applied after the holder translation
    The shared tilt was applied to the holder-1 pose before the per-holder
    translation, so the 30(N-1) mm step ran along the tilted tool y and
    dragged holder N 0.157(N-1) mm off the stack axis at 0.3 deg — three
    times the seat clearance, and every angle change moved every holder.
    Turning about each holder's own grasp point after the translation makes
    the angle position-invariant; holder_multi_tilt_x_deg (holder N at
    index N-2, added to the shared angle) carries per-holder seat lean.
    [taught_waypoints.yaml]
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2026-08-18 sequence: add holder map mode (CalibMode=6)
    One trigger probes one holder: fetch the puck from MapSource via the
    sample holder (or pick it in place), run the seat probe without a jog
    hold, leave the puck seated. Replaces the external caput orchestration
    that drove the same tour through StartStep/PauseStep/Wait; the new
    Robot:MapSource record is optional, so an older IOC database still
    serves a working daemon.
    [main.rs, sequencer.yaml, sequencer_ursim.yaml]
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2026-08-18 waypoints: raise the base-y trim for holders 7-9
    The 7-9 extraction jams were never bottoming: the seat forces show the
    puck pressed into its -y wall (+30..38 N reaction) and the arm's
    holder_on_lift then tensioning against the stuck puck (-38..-48 N).
    The response is binary, not proportional — holder 9 freed at +0.05 mm
    and 7/8 each needed +0.10 mm; probes after the change measure all
    three within 0.02 mm of the bore centre in y.
    [taught_waypoints.yaml]
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2026-08-18 waypoints: add a per-holder insertion-depth trim
    holder_multi_y_offsets completes the per-holder basis: x and z existed,
    but a seat's own depth error had no knob. All zeros for now — holder
    10's probes put its floor error at 0.019 mm (0.131 mm to floor against
    the 0.150 mm hover), so its residual tension is the rail-end +y
    interference, not depth; the knob is for the day a seat actually
    needs one.
    [taught_waypoints.yaml]
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2026-08-18 waypoints: centre the stage-seat release from the probe
    The seat probe measured the puck rest 0.329 mm (base x) and
    -0.285 mm (base y) off the recess centre. At sample_holder_on the
    tool frame maps x->base +y and z->base -x, so the correction lands
    on x_offset and z_offset. Validation re-probe: residuals -0.13/-0.11
    mm against ~0.15 mm wall-fit scatter and 1.8 mm per-side clearance.
    [taught_waypoints.yaml]
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2026-08-18 gripper: grip at 28 N and the Hand-E's slowest speed
    grip_force 0.3 -> 0.05 and grip_speed 0.2 -> 0.0: the puck hangs in
    the finger detent, so the carry needs almost none of 70 N, and the
    softer and slower the fingers arrive the less the puck is disturbed
    in its seat. The register floor is 20 N / 20 mm/s, not zero. Close
    stall position held at 0.0110-0.0114 m across a full cycle.
    [sequencer.yaml]
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2026-08-18 gui: rewrite the control GUI in Rust on rsdm, images over pvAccess
    robot_gui_rs replaces the silx panel as the launched GUI (the python
    one stays runnable). Camera frames come over PVA through a direct TCP
    connection because UDP 5076 is shared by several IOCs the way 5064 is;
    colour RGB8 arrives as ubyte Bytes, which RsdmImageView cannot draw,
    so a local widget textures it. The offsets table saves by textual edit
    like the sequencer's holder-map persist, so both writers preserve
    comments and survive each other. 3_Camera_Viewer launches the same
    binary with --camera and brings up the D405 IOC if it is down.
    [main.rs]
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2026-08-18 sequence: fail a close step whose fingers gripped nothing
    A close that settles narrower than gripper.min_grip_position closed on
    its own pads, and every later step would build on an empty hand — the
    probe would sweep air and mode 6 would map an empty seat. Only hand()
    enforces it: the manual Gripper-PV path must keep serving an operator
    closing an empty gripper, and the simulated backend always reaches the
    command exactly, so it is exempt. Set to 8 mm against the 11.4 mm neck
    grip and the 3.9 mm false grip measured over holder 2's emptied seat.
    [sequencer.yaml]
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2026-08-19 probe: give holder wells their own profile, apart from the stage bore
    The wells are an order of magnitude tighter than the bore probe.lateral
    was tuned for, so every wall landed inside the first 0.05 mm step and the
    remainder was driven into it past abort_n; and persist_seat_centres read
    the same step_mm as its deadband, which left a well no writable window at
    all. BoreConfig and WellConfig now carry their own numbers, and WellConfig
    has no loosen_mm at all — clamped is what seat_probe() builds, so no
    config can ask for the loosened probe that tipped h2's puck out.
    [main.rs, probe.rs, sequencer.yaml]
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2026-08-19 map: locate the seat in all three axes before writing any trim
    The floor was measured and thrown away, so a map could correct a holder
    sideways while leaving its depth wherever the teaching guessed. The
    depth trim is floor − holder_on_position_lift, since the taught pose
    hovers by that lift on purpose, and a missing axis now refuses the whole
    write by name rather than moving the pose in a plane whose third
    coordinate is unknown. Wells get their own depth geometry for the same
    reason they got their own lateral one: at 0.10 mm steps the 0.15 mm
    hover is one or two samples, which is what left h7 with no floor to fit.
    [main.rs, probe.rs, sequencer.yaml]
2026-08-19 gripper: retune min_grip_position onto settle widths
    The 8 mm threshold was read off the close's band-exit values, which
    reported 11.0-11.4 mm whether or not anything was between the fingers.
    Now that a close ends on the fingers stopping, a held puck settles at
    3.9 mm and free air at 0.7 mm (both measured at holder 7), so 8 mm sat
    above a real grip and failed every successful pick.
    [sequencer.yaml]
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2026-08-19 probe: climb a well straight, and centre only in the bore
    Yielding sideways needs somewhere to yield into. The bore's 0.50 mm of
    radial clearance has it; a well's 0.05 mm does not, and at h7 the
    correction never converged -- it spent its whole 1.00 mm allowance
    inside 0.30 mm of climb while the load went 2.55, 0.70, 5.68, 1.20,
    5.46 N. What a well has instead is the taught corridor the production
    sequence lifts through every cycle, so `centring` moves into
    `BoreConfig` and a well climbs the line it was taught, with `abort_n`
    still reading every step.
    [probe.rs]
2026-08-19 probe: probe the floor where it has room to be approached
    A probe measures a distance it travels, and at the seat there is none:
    the taught pose holds the puck against the floor, so h7's downward step
    commanded 0.050 mm, moved 0.001 mm and loaded 0.43 N -- below the
    contact threshold, so the run died on the step-taken guard instead of
    reporting a depth. The floor probe moves to the top of `heights_mm`,
    where the same lift that gives the brackets their clearance gives it an
    approach, and `Seat::floor_mm` is converted back to the taught pose so
    every trim is still written in that frame.
    [sequencer.yaml]
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
